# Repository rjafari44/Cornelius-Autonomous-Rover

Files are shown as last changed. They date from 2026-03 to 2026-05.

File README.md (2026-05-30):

# Cornelius Autonomous Rover

#### This project uses an ESP32 microcontroller, ultrasonic sensor, servo motor, and a custom wireless controller to create an obstacle-avoiding and manually-driven rover called **Cornelius**. The rover communicates with the controller over ESP-NOW and supports both autonomous obstacle avoidance and real-time manual control. Included are STL files for 3D printing, a circuit schematic, images, and a parts list. The project is divided into Mechanical, Electrical, and Programming sections for clarity.

---

## Table of Contents
1. [Parts List](#parts-list)
2. [Mechanical](#mechanical)
3. [Electrical](#electrical)
4. [Programming](#programming)
5. [Movement Logic](#movement-logic)
6. [Usage](#usage)
7. [Legacy Version](#legacy-version)

---

### Image of Rover:
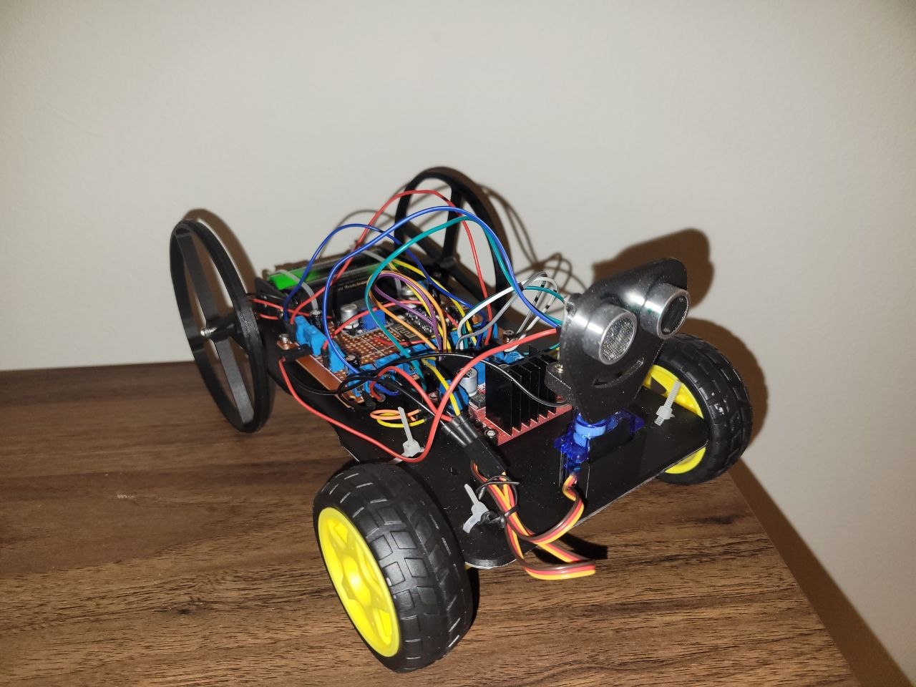
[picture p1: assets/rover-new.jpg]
Rover


---

## Parts List:

**Rover:**
- WeAct Studio ESP32-C3Fx4 Mini Core
- HC-SR04 ultrasonic distance sensor
- 2× TT DC gear motors
- 2× TT motor wheels
- Two port screw terminals
- L298N motor driver
- Micro servo (sg90)
- 2× 18650 Li-ion batteries (with holder)
- 3x 100 uF electrolytic capacitor
- 3x 0.1 uF ceramic capacitor
- 1x 10 uF ceramic capacitor
- LM2596 adjustable buck converter set to 5V
- dupont jumper wires
- 3D-printed chassis, wheels, and wheel mounts (PLA)
- Zipties
- bolts, washers, bearings (for wheel mounting)
- Electrical tape (for servo fitment)

**Controller:**
- WeAct Studio ESP32-C3Fx4 Mini Core
- Analog joystick module
- Push button (mode toggle)
- Green and red LEDs
- Custom PCB (see [Electrical](#electrical))
- 3D-printed enclosure (optional)

---

## Mechanical:
The chassis is custom-designed, and the wheels are inspired by a design from Prof. Wolken at Irvine Valley College. The ultrasonic sensor bracket is not included in this repository — many suitable brackets can be found online (e.g., searching "HC-SR04 bracket" on Printables).

- **Printing:** Chassis, wheels, and wheel mounts were 3D printed with PLA
- **Chassis Features:**
  - Holes for zipties to secure motors and components
  - Holes for routing TT motor wires to the motor driver
  - Bracket for the servo motor
- **Wheels & Mounts:**
  - Front wheels mounted to motors with zipties
  - Rear wheel mounts printed separately and attached via bolts through the chassis
  - Rear wheels attached via bolts through the mount bracket and two bearings for each
- **Component Mounting:** Motor driver and battery holder secured with tabs on the chassis
- **Ultrasonic Sensor:** Custom bracket (found online) reinforced with screws and washers for stability
- **Servo Motor:** MG90 (metal gears, overkill for this project — an SG90 or similar plastic gear servo works fine)
- **Notes:** Some wheel wobbling may occur, especially during extended operation

#### Assembly on Onshape:

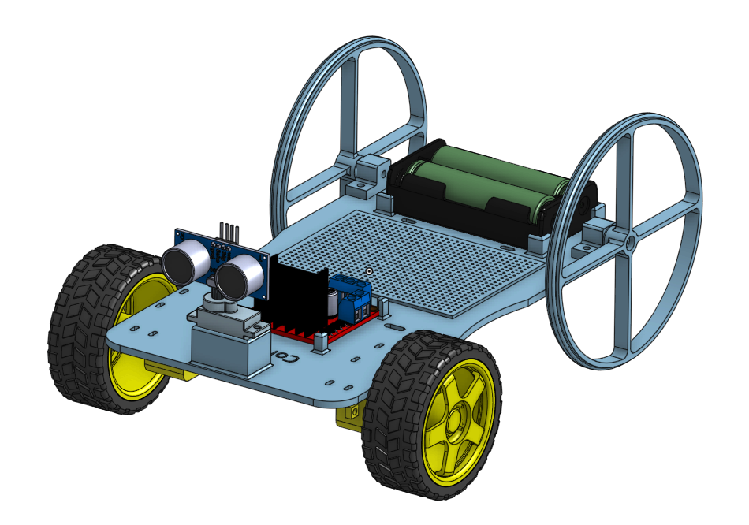
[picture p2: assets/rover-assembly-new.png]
Assembly


*The Onshape assembly file shows the rough placement of parts. Components are not fully constrained or mated, so this is meant as a visual reference only. Assembly file is provided.*

---

## Electrical:
The rover is powered by two 18650 Li-ion batteries in series (nominal 3.7 V each, 7.4 V total).

**Rover:**
- **Voltage Considerations:**
  - ESP32 VIN: 5V from buck converter
  - SG90 servo: 5V from buck converter
  - Actual battery voltage ~8 V, sufficient for this setup
- **Motors:** TT motors (3–6 V), voltage drop across the motor driver brings them into the safe range
- **Logic Power:** L298N motor driver has a built-in 5 V regulator which powers the ESP32, HC-SR04, and servo
- **Capacitors:** Placing them across the power rail and GND smooths voltage spikes, refer to the schematic for locations
- **Wiring:** Dupont jumper wires were used. Ensure solid connections to avoid intermittent failures
- **Current Draw:** Total current should realistically not exceed 2 A

**Controller:**
- A custom PCB was designed for the controller to clean up wiring and keep the build compact. PCB design files (schematic, layout, Gerbers) are hosted in a separate repository: [Controller PCB Repo](https://github.com/rjafari44/ESP32-Remote-Control-PCB)
- The controller is powered separately (USB or onboard regulation depending on your build)

#### Circuit Schematic:

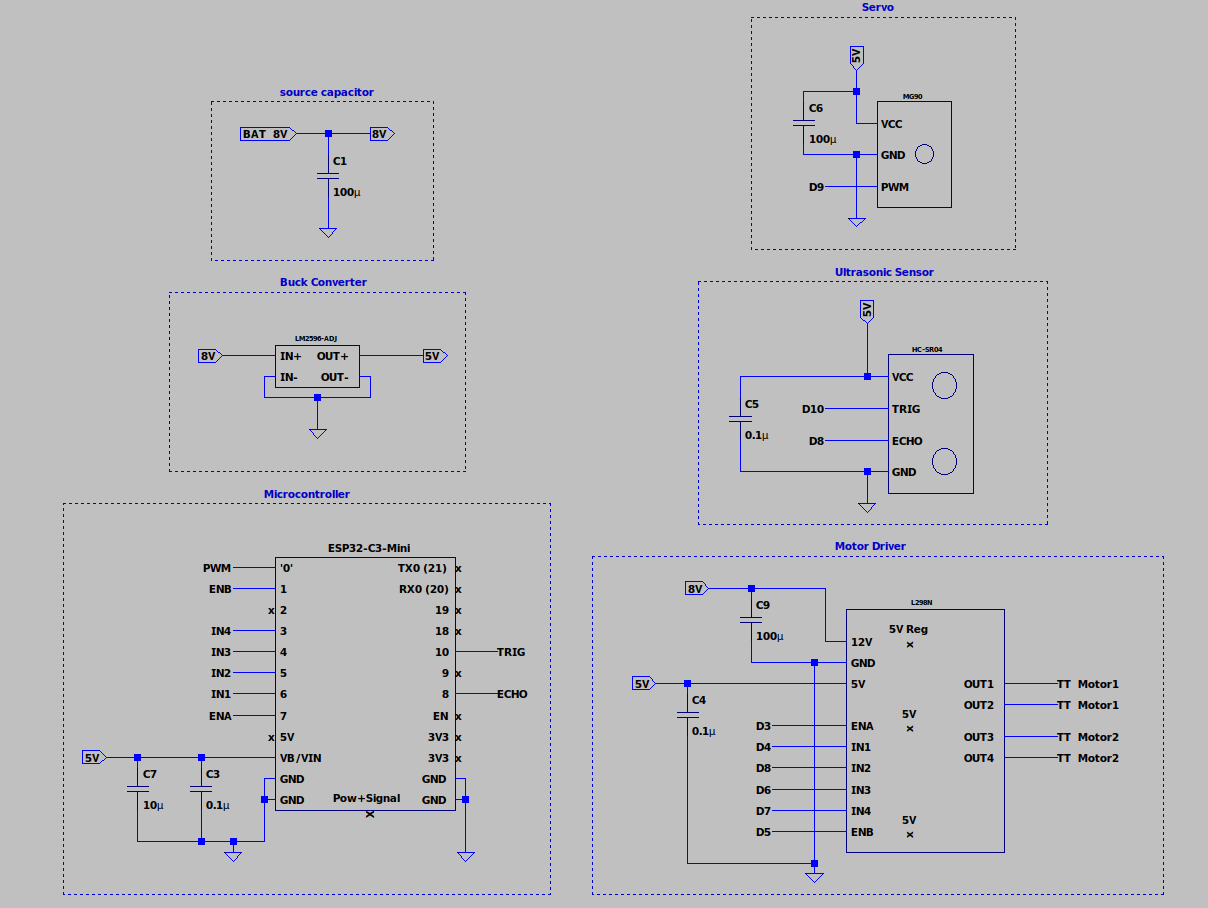
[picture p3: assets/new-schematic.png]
Schematic


---

## Programming:
The rover and controller each run on separate ESP32 boards and communicate wirelessly over **ESP-NOW** on channel 1. The controller sends a `ControlData` packet at 30 ms intervals containing joystick X/Y values and a mode flag. The rover acts on each packet immediately or stops if no packet is received within the failsafe window.

```cpp
typedef struct {
  int  x;
  int  y;
  bool autonomous;
} ControlData;
```

Both codebases are split across multiple `.cpp` files with a shared `common.h`.

**Rover files:**
| File | Purpose |
|---|---|
| `rover.ino` | Setup, main loop, failsafe, variable definitions |
| `control.cpp` | `manualControl()` and `autonomousDrive()` logic |
| `move.cpp` | Motor direction functions |
| `distance.cpp` | Ultrasonic sensor averaging |
| `look.cpp` | Servo sweep left/right for obstacle scanning |
| `data.cpp` | ESP-NOW receive callback |
| `common.h` | Pins, constants, struct, extern declarations |
| `servoDeclare.h` | Servo object declaration |

**Controller files:**
| File | Purpose |
|---|---|
| `controller.ino` | Setup, main loop, button handling, variable definitions |
| `input.cpp` | `proportional()` joystick scaling |
| `led.cpp` | `updateLEDs()` direction indicators |
| `common.h` | Pins, constants, struct, extern declarations |

- **Compilation:** Arduino IDE or Arduino CLI
- **Shell Script:** Provided (`run.sh`) to simplify CLI compilation. Ensure it has executable permissions (`chmod +x run.sh`)

---

### Failsafe:
If the rover does not receive a packet within `FAILSAFE_MS` (500 ms), it stops all motors until communication resumes:

```cpp
if (!hasPacket || millis() - lastPacketTime > FAILSAFE_MS) {
  stopMotors();
  return;
}
```

---

### Mode Switching:
The joystick button toggles between **manual** and **autonomous** mode. The `autonomous` flag is packed into every ESP-NOW transmission and read on the rover side each loop:

```cpp
autonomousMode = rx.autonomous;

if (autonomousMode) {
  autonomousDrive();
} else {
  manualControl(rx.x, rx.y);
}
```

Both LEDs lighting up simultaneously on the controller indicates autonomous mode is active.

---

### Manual Control:
Joystick input is read, smoothed with a rolling average, and mapped through `proportional()` to correct for the off-center neutral point of the joystick:

```cpp
lastX = (lastX * 3 + x) / 4;
lastY = (lastY * 3 + y) / 4;

int mappedX = proportional(lastX, CENTER_X, DEADZONE);
int mappedY = proportional(lastY, CENTER_Y, DEADZONE);
```

On the rover, the dominant axis wins — if vertical deflection is greater than horizontal, the rover moves forward or backward; otherwise it turns:

```cpp
if (abs(y) >= abs(x)) {
  // forward / backward
} else {
  // turn left / right
}
```

---

### Autonomous Drive:
In autonomous mode the rover moves forward freely until an obstacle is detected within `OBSTACLE_LIMIT` (20 cm). It also performs a proactive sweep every `SWEEP_INTERVAL` (5 seconds) even on a clear path, nudging toward whichever side has more room:

```cpp
if (now - lastSweepTime >= SWEEP_INTERVAL) {
  int leftDist  = lookLeft();
  int rightDist = lookRight();

  if (leftDist > rightDist + 10)       { turnLeft();  delay(200); }
  else if (rightDist > leftDist + 10)  { turnRight(); delay(200); }
}
```

When an obstacle is detected, the rover stops, backs up, then scans left and right with the servo to pick the clearer direction:

```cpp
int leftDist  = lookLeft();
int rightDist = lookRight();

if (leftDist < OBSTACLE_LIMIT && rightDist < OBSTACLE_LIMIT) {
  moveBackward();   // both blocked — keep reversing
  return;
}

if (leftDist > rightDist) { turnLeft(); }
else                       { turnRight(); }
```

---

## Movement Logic:

| Movement | IN1 | IN2 | IN3 | IN4 | ENA | ENB |
|---|-----|-----|-----|-----|-----|-----|
| Forward | 0 | 1 | 0 | 1 | PWM | PWM |
| Backward | 1 | 0 | 1 | 0 | PWM | PWM |
| Turn Left  | 1 | 0 | 0 | 1 | PWM | PWM |
| Turn Right | 0 | 1 | 1 | 0 | PWM | PWM |
| Stop | — | — | — | — | 0 | 0 |

**0 = Low**\
**1 = High**\
**PWM = 0–255 analog value (set via `MOTOR_SPEED` constant)**

---

## Usage:

#### 1. Flash Both Boards
Flash `rover.ino` to the rover ESP32 and `controller.ino` to the controller ESP32. Make sure both are on the same ESP-NOW channel (channel 1 by default) and that the rover's MAC address in `controller.ino` matches your actual hardware.

#### 2. Find Connected Serial Port

**On Linux:**
```bash
ls /dev/tty*
```

**With Arduino CLI (recommended):**
```bash
arduino-cli board list
```

#### 3. Run the Programs
Separate shell scripts are provided for each board. Ensure they have executable permissions before running:

```bash
chmod +x run_rover.sh run_controller.sh
```

**Rover:**
```bash
./run_rover.sh
```

**Controller:**
```bash
./run_controller.sh
```

---

## Legacy Version

An earlier version of Cornelius ran on an **Arduino Nano** with no wireless controller and supported only autonomous obstacle avoidance. That version is preserved in the [`legacy/`](legacy/) directory at the root of this repository.

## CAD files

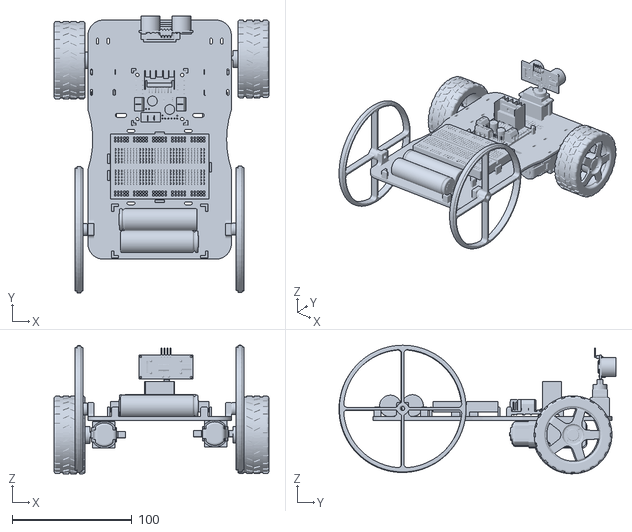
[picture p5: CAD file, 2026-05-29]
cad-files/assembly.stl
179.5 x 231.6 x 107.5

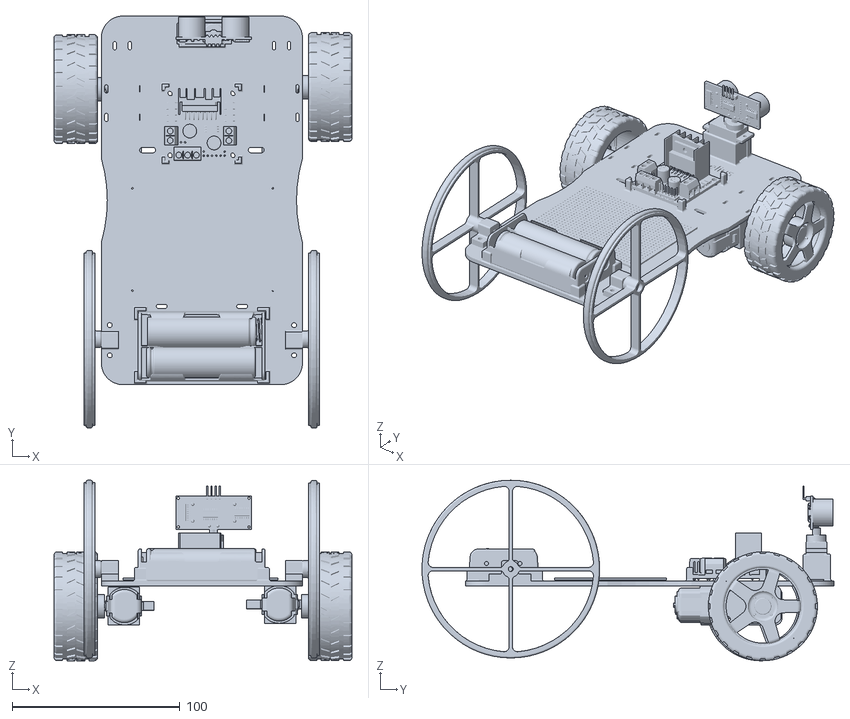
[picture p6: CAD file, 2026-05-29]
cad-files/new/rover_assembly_new.stl
177.8 x 245.8 x 107.7

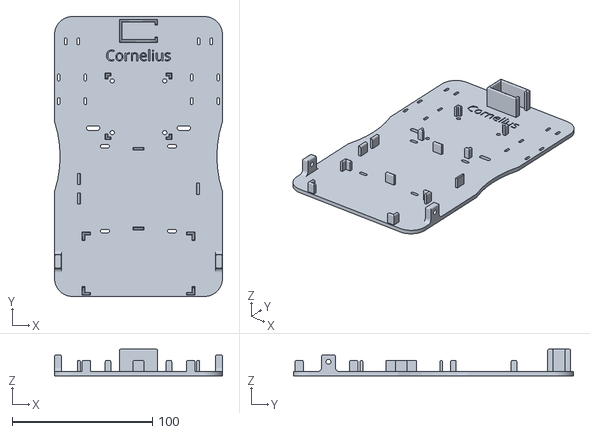
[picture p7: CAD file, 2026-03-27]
cad-files/chassis.stl
120.0 x 200.0 x 19.0

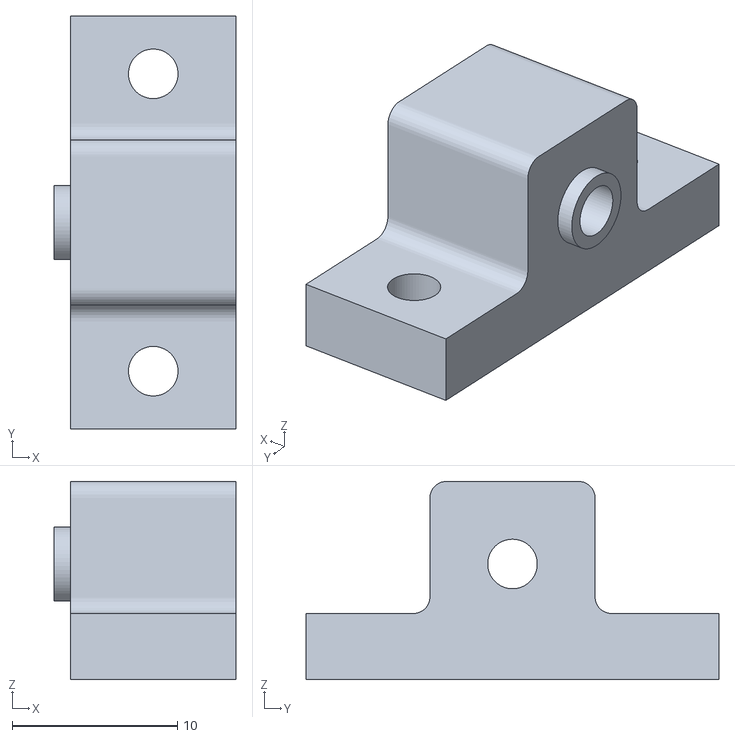
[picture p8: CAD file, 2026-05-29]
cad-files/new/wheel_mount.stl
11.0 x 25.0 x 12.0

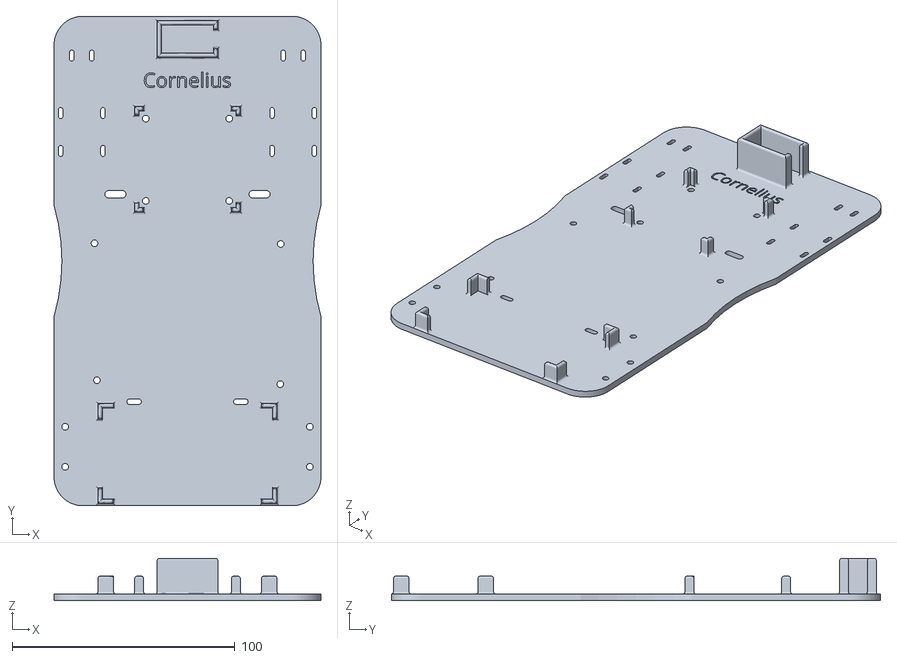
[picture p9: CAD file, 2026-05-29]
cad-files/new/frame_updated.stl
120.0 x 220.0 x 19.0

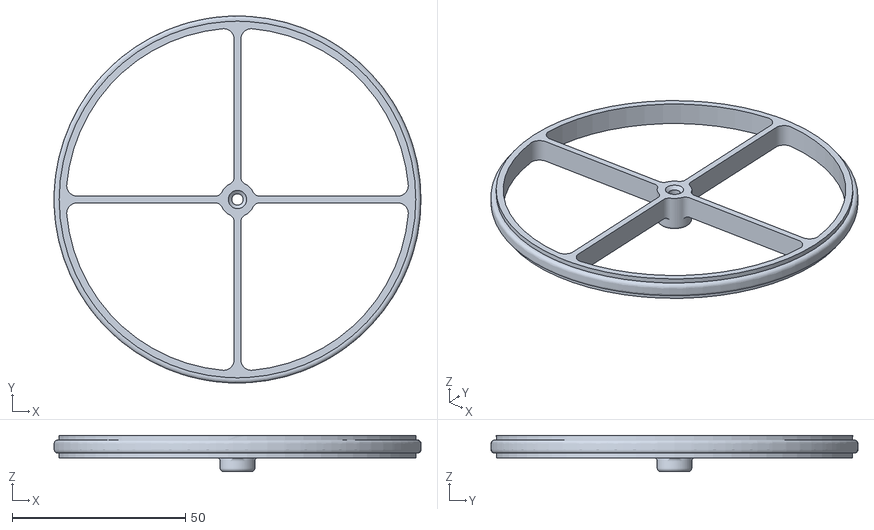
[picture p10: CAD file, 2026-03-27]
cad-files/new/wheel.stl
106.0 x 106.0 x 10.5

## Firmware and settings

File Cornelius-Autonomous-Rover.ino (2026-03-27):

#include "common.h"

constexpr int OBSTACLE_LIMIT{20};              // set detection limit (20 cm)
constexpr unsigned long FORWARD_TIMEOUT{3000}; // variable to limit movement after set time

// function for setting up the arduino code, runs once, returns nothing
void setup() {
  // setting the l298n pins as output
  pinMode(ENA, OUTPUT);
  pinMode(ENB, OUTPUT);
  pinMode(IN1, OUTPUT);
  pinMode(IN2, OUTPUT);
  pinMode(IN3, OUTPUT);
  pinMode(IN4, OUTPUT);

  // setup the ultrasonic pins
  pinMode(trigPin, OUTPUT);
  pinMode(echoPin, INPUT);

  // setup the servo 
  myServo.attach(SERVO_PIN);
  myServo.write(90); // center
  delay(1000);
}

// function for running the arduino code, loops, returns nothing
void loop() {
  int distance{};               // variable of integer type for distance to an object
  int leftDist{};               // variable of integer type for distance to an object on the left side
  int rightDist{};              // variable of integer type for distance to an object on the right side
  bool obstacleDetected{};      // variable of boolean type for object detected
  bool forwardTimeoutReached{}; // variable of boolean type for forward movement
  static unsigned long forwardStartTime{};         // variable to track time since movement

  distance = getDistance();  // get distance to object

  // if obstacle is detected within detection limit, set true, otherwise false
  obstacleDetected = (distance <= OBSTACLE_LIMIT);

  // if time since movement is not zero and time elapsed is more than 3 seconds, set true, otherwise false
  forwardTimeoutReached = (forwardStartTime != 0 && millis() - forwardStartTime >= FORWARD_TIMEOUT);

  // Start forward motion if path is clear and not already moving
  if (distance > OBSTACLE_LIMIT && forwardStartTime == 0) {
    moveForward();
    forwardStartTime = millis();
  }

  // If timeout reached, re-check path and keep going if clear
  if (forwardTimeoutReached) {
    forwardStartTime = millis(); // reset timer
    distance = getDistance();    // re-check distance
    if (distance > OBSTACLE_LIMIT) {
      moveForward();
      return;
    }
    obstacleDetected = true; // path is blocked, fall through to avoidance
  }

  // Run obstacle avoidance only if an obstacle is actually detected
  if (obstacleDetected) {
    stopMotors();
    forwardStartTime = 0; // reset timer

    // Back up a bit
    delay(200);
    moveBackward();
    delay(300);
    stopMotors();

    // Look left and right
    leftDist = lookLeft();
    rightDist = lookRight();

    // Decide which way to turn
    if (leftDist > rightDist) {
      turnLeft();
    } else {
      turnRight();
    }

    delay(400);
    stopMotors();
  }
}

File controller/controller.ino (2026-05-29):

#include "common.h"

// rover MAC address
uint8_t roverAddress[] = {0xA8, 0x46, 0x74, 0x5C, 0x1A, 0x7C};

// struct object
ControlData data;

// joystick states
int  lastX      = CENTER_X;
int  lastY      = CENTER_Y;
bool autonomous = false;

unsigned long lastSend  = 0;

// button state tracking
bool lastBtnState = HIGH;

// main setup
void setup() {
  Serial.begin(115200);

  pinMode(JOY_BTN, INPUT_PULLUP);
  pinMode(LED_GREEN, OUTPUT);
  pinMode(LED_RED, OUTPUT);
  digitalWrite(LED_GREEN, LOW);
  digitalWrite(LED_RED, LOW);

  WiFi.mode(WIFI_STA);

  if (esp_now_init() != ESP_OK) {
    Serial.println("ESP-NOW init failed");
    return;
  }

  esp_now_peer_info_t peer = {};
  memcpy(peer.peer_addr, roverAddress, 6);
  peer.channel = 1;   // explicit channel which must match rover
  peer.encrypt = false;
  esp_now_add_peer(&peer);

  Serial.println("Controller ready — hold joystick button 3s to toggle auto/manual");
}

// main loop
void loop() {

  // button press detection (falling edge, runs every iteration)
  bool btnState = digitalRead(JOY_BTN);

  if (lastBtnState == HIGH && btnState == LOW) {
    autonomous = !autonomous;

    Serial.printf("Mode toggled -> %s\n", autonomous ? "AUTONOMOUS" : "MANUAL");

    digitalWrite(LED_GREEN, HIGH);
    digitalWrite(LED_RED,   HIGH);
    delay(100);
    digitalWrite(LED_GREEN, LOW);
    digitalWrite(LED_RED,   LOW);
  }
  lastBtnState = btnState;

  // throttle send rate (no early return — button must always run)
  if (millis() - lastSend >= SEND_INTERVAL) {
    lastSend = millis();

    int x = analogRead(JOY_X);
    int y = analogRead(JOY_Y);

    lastX = (lastX * 3 + x) / 4;
    lastY = (lastY * 3 + y) / 4;

    int mappedX = proportional(lastX, CENTER_X, DEADZONE);
    int mappedY = proportional(lastY, CENTER_Y, DEADZONE);

    updateLEDs(mappedX, mappedY);

    data.x          = mappedX;
    data.y          = mappedY;
    data.autonomous = autonomous;

    Serial.printf("TX -> X:%d  Y:%d  Mode:%s\n",
                  mappedX, mappedY,
                  autonomous ? "AUTO" : "MANUAL");

    esp_now_send(roverAddress, (uint8_t*)&data, sizeof(data));
  }
}

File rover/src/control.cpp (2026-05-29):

#include "common.h"

// function for manually controlling the rover
void manualControl(int x, int y) {

  if (x == 0 && y == 0) {
    stopMotors();
    return;
  }

  if (abs(y) >= abs(x)) {

    if (y > 0) {
      moveBackward();
    }
    else {
      moveForward();
    }

  } else {

    if (x > 0) {
      turnRight();
    }
    else {
      turnLeft();
    }
  }
}

// function for autonomous control
void autonomousDrive() {

  static unsigned long lastMoveTime{0};
  unsigned long now{millis()};

  int d1 = getDistance();
  delay(5);
  int d2 = getDistance();

  int distance = (d1 + d2) / 2;

  // safe path to move forward
  if (distance > OBSTACLE_LIMIT) {

    if (millis() - lastMoveTime > 200) {
      moveForward();
      lastMoveTime = millis();
    }

    // five second sweep
    if (now - lastSweepTime >= SWEEP_INTERVAL) {

      lastSweepTime = now;

      stopMotors();
      delay(80);

      int leftDist = lookLeft();
      int rightDist = lookRight();

      if (leftDist > rightDist + 10) {
        turnLeft();
        delay(200);
      }
      else if (rightDist > leftDist + 10) {
        turnRight();
        delay(200);
      }

      stopMotors();
    }

    return;
  }

  // obstacle detected
  stopMotors();
  delay(150);

  moveBackward();
  delay(300);

  stopMotors();

  int leftDist = lookLeft();
  int rightDist = lookRight();

  if (leftDist < OBSTACLE_LIMIT && rightDist < OBSTACLE_LIMIT) {
    moveBackward();
    delay(300);
    return;
  }

  if (leftDist > rightDist) {
    turnLeft();
  } else {
    turnRight();
  }

  delay(350);

  stopMotors();
}

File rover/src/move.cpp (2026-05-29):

#include "common.h"

// function for moving forward
void moveForward() {

  digitalWrite(IN1, LOW);
  digitalWrite(IN2, HIGH);

  digitalWrite(IN3, LOW);
  digitalWrite(IN4, HIGH);

  analogWrite(ENA, MOTOR_SPEED);
  analogWrite(ENB, MOTOR_SPEED);
}

// function for moving backwards
void moveBackward() {

  digitalWrite(IN1, HIGH);
  digitalWrite(IN2, LOW);

  digitalWrite(IN3, HIGH);
  digitalWrite(IN4, LOW);

  analogWrite(ENA, MOTOR_SPEED);
  analogWrite(ENB, MOTOR_SPEED);
}

// function for turning left
void turnLeft() {

  digitalWrite(IN1, HIGH);
  digitalWrite(IN2, LOW);

  digitalWrite(IN3, LOW);
  digitalWrite(IN4, HIGH);

  analogWrite(ENA, MOTOR_SPEED);
  analogWrite(ENB, MOTOR_SPEED);
}

// function for turning right
void turnRight() {

  digitalWrite(IN1, LOW);
  digitalWrite(IN2, HIGH);

  digitalWrite(IN3, HIGH);
  digitalWrite(IN4, LOW);

  analogWrite(ENA, MOTOR_SPEED);
  analogWrite(ENB, MOTOR_SPEED);
}

void stopMotors() {

  analogWrite(ENA, 0);
  analogWrite(ENB, 0);
}

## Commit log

2026-03-27 renamed some files
    [chassis.stl, wheel.stl]
2026-05-23 added schematic and symbols
2026-05-24 updated schematic
2026-05-25 current mess
2026-05-25 fixed the issue, capacitor needed across joystick to stabilize
    [rover.ino]
2026-05-28 fixed a bunch of bugs
    [rover.ino]
2026-05-29 updated README and added cad files
    [assembly.stl, chassis.stl, frame_updated.stl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]
2026-05-29 added images and cad files
    [rover-assembly-new.stl]
2026-05-29 renamed cad file
    [wheel_mount.stl]
2026-06-12 renamed the file
    [rover_assembly_new.stl]
